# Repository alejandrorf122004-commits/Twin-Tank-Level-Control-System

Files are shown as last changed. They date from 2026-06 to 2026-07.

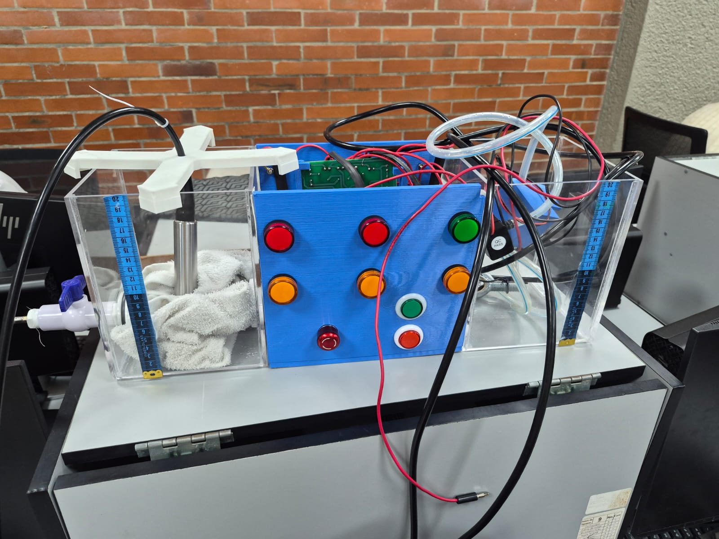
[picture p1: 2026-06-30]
Images/MONTAJE_FISICO.jpeg

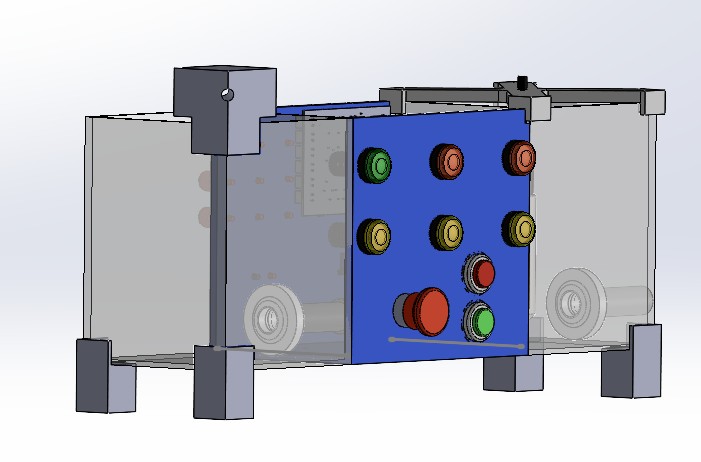
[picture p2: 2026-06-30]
Images/ISOMETRICO CAD.jpg

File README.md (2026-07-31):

# Twin Tank Level Control System

Coupled-tank control project with CAD, MATLAB, Python GUI, observer design and PLC-oriented implementation.

## Purpose

This project documents the modeling, simulation and control of a twin-tank hydraulic system used to study process control and reference tracking.

## What is included

- `CAD/`: mechanical design, assemblies and PCB references.
- `MATLAB/`: modeling, controller design and observer work.
- `Python_GUI/`: interface for simulation and data analysis.
- `Documentation/`: final report and supporting documents.
- `Images/`: CAD renders, GUI captures and prototype photos.

## Main focus

- Second-order process modeling
- PID and state-space control
- State observer design
- Servosystem implementation
- GUI support for analysis and validation

## Current status

The repository presents the project as a technical control-system development with documentation, simulations and prototype evidence.

## Authors

**Alejandro Ramírez Forero**  
Mechatronics Engineering Student  
Bogotá, Colombia

**Daniel Felipe Meneses Barreto**  
GitHub: _add profile link here if available_

**Juan Esteban Parrado**  
GitHub: _add profile link here if available_

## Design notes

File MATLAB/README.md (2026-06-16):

# MATLAB Files

MATLAB scripts for modeling, transfer function derivation, controller design, observer design and simulations.
# MATLAB Design Workflow

The scripts are executed sequentially because variables generated in each stage are used by subsequent stages.

Execution order:

1. 01_Calculo_Resistencias_Hidraulicas.mlx
   - Hydraulic parameter calculation.

2. 02_TF_Tanques.mlx
   - Transfer function derivation.

3. 03_Control_Tanques.mlx
   - PI and PD controller design.

4. 04_Espacio_Estados_Observador.mlx
   - State-space representation and observer design.

5. 05_Servo_Con_Observador.mlx
   - Observer-based servosystem implementation.

Important:
Run the scripts in the specified order because they share workspace variables.

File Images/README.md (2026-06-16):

# Images

Project photographs, CAD renders and simulation screenshots.

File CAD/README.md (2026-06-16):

# CAD Models

This folder contains the SolidWorks CAD files and mechanical design documentation of the twin-tank level control system.

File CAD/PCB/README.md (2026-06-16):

# PCB Models

PCB mechanical models and electronic enclosure integration.

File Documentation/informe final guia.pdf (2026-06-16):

Periodo 2026-1

# GUÍA FINAL GEMELO DIGITAL PARA

LA AUTOMATIZACIÓN DE PROCESO.

Daniel Felipe Meneses Barreto – Alejandro Ramírez Forero – Juan Esteban Parrado Rendon.

{ est.daniel.meneses, est.alejandro.ramif, est.juan.parrado }@unimilitar.edu.co

Profesora: Olga Lucia Ramos Sandoval

Resumen — Como se mencionó en el primer corte de la materia se tomó la decisión de automatizar una línea de producción de pasta dental, contando con 3 pasos esenciales durante el proceso, limpieza del agua, creación de la mezcla de pasta dental, empaquetado del mismo. Para el proyecto contamos con una planta física (se decide hacer un control de nivel) además de contar con un gemelo digital tridimensional desarrollado sobre el motor de simulación avanzada Unity 3D. Se llevo a cabo el establecer un entorno integrando la planta física de control, comunicándose con el PLC y a la vez del entorno virtual, contando con los mismos valores del control de velocidad y el posicionamiento del servomotor, logrando el objetivo de simular el accionar de la planta de producción de pasta dental además de lograr una comunicación entre entornos y montajes. Se construyó un módulo físico con una PCB de distribución y 2 taques en acrílico para el llenado y vaciado de los mismo), sensor de presión hidrostática para el nivel analógico, luces de señalización y botones de operación (start, stop, emergencia). En software, se programó en Unity 3D se simularon los llenados del tanque y del movimiento del variador (simulando el emulsionador) además de simular el empaquetado de cada lote de pasta dental, usando el servomotor para el posicionamiento de cada tubo de pasta dental (cajas de a 3 unidades). El gemelo digital replicó de forma idéntica la sincronización operativa de la planta física, logrando manipular el variador y el servomotor según lo deseado, logrando el proceso deseado para la creación de pasta dental, contando con alarmas en el caso de que no se realice un buen proceso.

Abstract— This paper presents the design and implementation of an automated toothpaste production line consisting of three main stages: water purification, mixture preparation, and final product packaging. The proposed system integrates a physical level-control plant with a three-dimensional digital twin developed in Unity 3D, enabling real-time synchronization between both environments through communication with a Programmable Logic Controller (PLC). The implemented architecture reproduces the operational variables of the physical plant, including variable frequency drive (VFD) speed control and servo motor positioning, to accurately emulate the behavior of the industrial process. The physical platform was constructed using a distribution printed circuit board (PCB), two acrylic tanks for filling and draining operations, a hydrostatic pressure sensor for analog level measurement, status indicator lights, and an operator interface composed of start, stop, and emergency pushbuttons. In the software environment, dynamic models were developed in Unity 3D to simulate tank-filling operations, the operation of an emulsifier driven by the VFD, and the packaging process of toothpaste batches, where a servo motor was employed to position toothpaste tubes into packages containing three units. The developed digital twin faithfully replicated the operational synchronization of the physical plant, enabling monitoring and control of the production process while providing alarm mechanisms for the detection of abnormal operating conditions.

I. INTRODUCCIÓN.

El diseño de líneas de producción automatizadas dedicadas a productos de cuidado personal, específicamente la pasta dental en este caso exige una gestión rigurosa de los procesos de mezcla química y dosificación continua [1]. La formulación de este producto combina agentes abrasivos, humectantes y espesantes que demandan condiciones controladas de homogeneización para asegurar un fluido consistente y funcional para el uso diario. Por consiguiente, la automatización industrial moderna busca regular con extrema precisión variables como la velocidad de agitación, el vacío y el nivel del fluido para evitar la formación de burbujas o discontinuidades en el producto terminado.

En este contexto, la implementación de sistemas de la planta fisica de control y gemelos digitales se ha consolidado como una herramienta fundamental en la ingeniería de empaque y manufactura automatizada [2]. Al acoplar entornos virtuales tridimensionales dinámicos con estaciones de control de hardware real, es posible supervisar de forma simétrica variables críticas sin comprometer la integridad de la maquinaria de planta [3]. Esta metodología permite simular el comportamiento cinemático y lógico de actuadores complejos como servomotores y variadores de frecuencia antes de su despliegue físico definitivo [4].

Silva y Torres [5] desarrollaron en 2024 un sistema de control predictivo para motores de inducción acoplados a variadores de frecuencia en procesos de agitación industrial de mezclas densas. Este estudio posee un alto interés para nuestro desarrollo debido a que provee las bases matemáticas de rampas de aceleración y desaceleración necesarias para programar el variador de velocidad del agitador de nuestro tanque, impidiendo cambios bruscos que deterioren la consistencia de la receta de pasta dental.

Asimismo, en el año 2024, Roberts et al. [6] investigaron el modelado analítico de dinámicas de segundo orden con retardos inherentes en tanques de almacenamiento empleando transductores de presión hidrostática sumergibles de 4–20 mA. Validando el comportamiento matemático de acumulación de nuestra variable analógica principal y sustenta la calibración del sensor de nivel físico integrado en el panel de control.

Por otra parte, Zhang y Müller [7] presentaron en 2025 un algoritmo de control distribuido aplicado a servomotores de alta resolución para el posicionamiento y alineación en milisegundos de contenedores plásticos bajo boquillas de llenado térmico. Fundamenta la lógica de control de posición exacta requerida por el servomotor virtual para centrar perfectamente cada tubo de 100 ml y mitigar derrames o la activación de la alarma por desalineación.

En el ámbito de la simulación tridimensional, Jackson y Peterson [8] demostraron en 2025 la viabilidad de utilizar el motor gráfico Unity 3D para emular flujos mecánicos complejos e interactivos en líneas de empaque en paralelo, sustituyendo los costosos softwares industriales cerrados. Este antecedente aporta un valor metodológico directo al0 proyecto, validando el uso de técnicas de simulación detallada y anulación cinemática temporal sobre bandas transportadoras virtuales para estabilizar el trayecto de los lotes trinos de tubos frente a las perturbaciones físicas del motor gráfico.

En 2026, Martinez y Zhou [9] propusieron un protocolo ciberfísico robusto para la integración de matrices de alarmas multinivel (LL y HH) conectadas a tarjetas de circuito impreso (PCB) y enclavamientos de seguridad por paradas de emergencia en entornos inteligentes. Este artículo es de interés para el desarrollo, ya que establece los criterios de diseño eléctrico y de enrutamiento de señales en la PCB física para que el botón de paro de emergencia y los sensores operen en perfecta sincronía con los eventos lógicos y visuales del gemelo digital.

El objetivo principal de este trabajo es diseñar, construir e integrar una planta fisica de control automatizada para la línea de fabricación, dosificación y empaque paralelo de pasta dental, articulando un panel de control físico interactivo y un gemelo digital detallado en Unity 3D [10]. A través de esta sinergia, se busca consolidar un sistema capaz de supervisar la variable analógica de nivel , gestionar dinámicamente variadores y servomotores bajo una receta estricta de 300 gramos , y garantizar la seguridad mediante la monitorización visual multicámara HMI y un esquema de cuatro alarmas críticas distribuidas.

II. METODOS Y MATERIALES.

Propuesta técnica:

El objetivo general de este proyecto es desarrollar la automatización de una línea de producción de pasta dental utilizando el equipo industrial de la plataforma SIMATIC S7-1500 y herramientas computacionales que permitan integrar las competencias desarrolladas en las áreas de automatización y control, electrónica, programación, mecánica y gestión de procesos. Como objetivos específicos se plantearon: realizar una gestión del proceso que permita su desarrollo adecuado, diseñar un entorno virtual tridimensional del proceso para ser interconectado al equipo real industrial, y entregar una solución de software que satisfaga los requerimientos del proceso automatizado.

La pasta dental es un producto de higiene bucal cuya fabricación involucra una serie de etapas físicas y químicas que deben ejecutarse de manera precisa y controlada para garantizar la calidad, consistencia y seguridad del producto final. El proceso abarca desde el tratamiento del agua utilizada como base líquida hasta el llenado y sellado de los tubos que contienen el producto terminado. Para efectos de este proyecto, el alcance del sistema automatizado comprende desde la etapa de mezcla de los ingredientes hasta el empaque de tres tubos de 100 ml de crema dental dentro de una caja, lo cual representa el núcleo productivo del proceso y la etapa con mayor complejidad desde el punto de vista del control automático.

El proceso inicia con el tratamiento del agua mediante un sistema de ósmosis inversa, el cual tiene como objetivo eliminar impurezas, minerales y contaminantes presentes en el agua de suministro, produciendo agua desionizada o purificada apta para uso en productos farmacéuticos y cosméticos. Esta etapa es fundamental ya que la calidad del agua afecta directamente la estabilidad química y microbiológica de la pasta dental. Aunque esta etapa no forma parte del alcance directo del sistema de control implementado, su producto, el agua purificada, es la materia prima principal que alimenta el proceso de mezcla y fue incluida en el entorno virtual como referencia contextual del proceso completo.

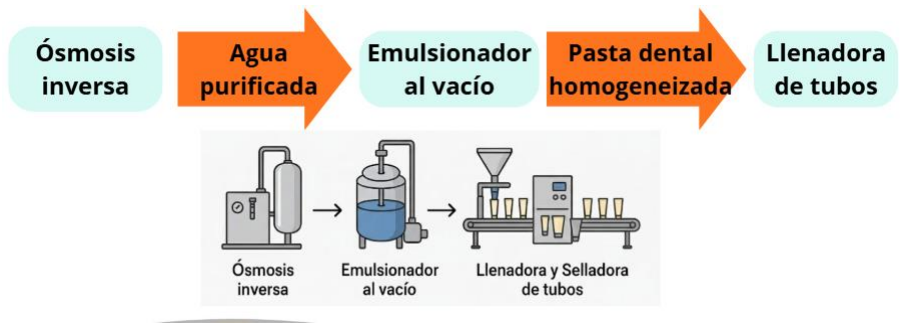
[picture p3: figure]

Figura 1. descripción general del proceso

La etapa central del proceso es la emulsificación al vacío, que se lleva a cabo en un tanque mezclador equipado con aspas de agitación. En esta etapa se incorporan de manera secuencial los ingredientes que componen la pasta dental: primero la base líquida conformada por el agua desionizada, el sorbitol y la glicerina, encargados de la humectación y la textura del producto; luego los modificadores de reología como la carboximetilcelulosa (CMC), que controlan la viscosidad y estabilidad de la mezcla; posteriormente los principios activos como el fluoruro de sodio para la protección dental; los abrasivos como la sílice hidratada o el carbonato de calcio, responsables de la acción de limpieza; los aromas y colorantes que definen las características organolépticas del producto; y finalmente el detergente, generalmente lauril sulfato de sodio (SLS), que favorece la formación de espuma durante el cepillado. La incorporación de estos ingredientes bajo condiciones de vacío evita la introducción de burbujas de aire en la mezcla, lo cual es crítico para la estabilidad y apariencia del producto final.

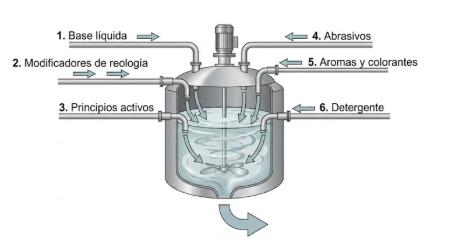
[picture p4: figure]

Figura 2. fase de emulsionado

Para la receta implementada en este proyecto, orientada a producir 300 gramos de pasta dental con menor abrasividad, se definieron proporciones específicas de cada ingrediente expresadas en porcentaje en peso. El agua desionizada representa el 42% de la formulación con 126 g, el sorbitol el 25% con 75 g, la glicerina el 6% con 18 g, la sílice hidratada el 15% con 45 g, el CMC el 1% con 3 g, el lauril sulfato de sodio el 1% con 3 g, el fluoruro de sodio el 0.32% con 0.96 g, la sacarina sódica el 0.20% con 0.6 g, el benzoato de sodio el 0.40% con 1.2 g, el aroma de menta el 1% con 3 g y el colorante el 0.08% con 0.24 g, totalizando 300 g de producto terminado. Esta receta fue parametrizada en el sistema de supervisión de forma que el operador pueda modificar las cantidades de los ingredientes editables dentro de rangos validados, activando una alarma en caso de que algún valor se encuentre fuera del rango permitido.

El mezclador es accionado por un variador de frecuencia, lo cual representa una ventaja técnica significativa frente al uso de un motor de velocidad fija. El variador de frecuencia permite regular la velocidad de agitación en función de la viscosidad de la mezcla calculada a partir de los ingredientes ingresados, de manera que mezclas más viscosas se procesan a menor velocidad para evitar esfuerzos mecánicos excesivos y garantizar una homogenización adecuada. Esta estrategia optimiza el consumo energético del sistema ya que el motor no opera siempre a máxima potencia, extiende la vida útil del equipo al reducir el desgaste mecánico en condiciones de alta carga, y mejora la calidad del producto al adaptar dinámicamente el proceso a las condiciones reales de la mezcla. En el sistema implementado, la velocidad del variador se determina automáticamente según tres rangos de viscosidad calculados a partir de la receta: para viscosidades entre 0 y 50 se asignan 1500 RPM con un tiempo de mezcla de 20 segundos, para viscosidades entre 50 y 80 se asignan 1000 RPM con 25 segundos, y para viscosidades entre 80 y 120 se asignan 500 RPM con 30 segundos.

Una vez completada la etapa de mezcla y alcanzado el nivel de llenado deseado en el tanque, el producto homogeneizado pasa a la etapa de llenado y sellado de tubos. Esta etapa es ejecutada por la empaquetadora controlada mediante un servomotor que acciona la banda transportadora. La elección del servomotor para esta aplicación obedece a sus características técnicas superiores frente a otros tipos de actuadores: el servomotor permite un control preciso de posición y velocidad, lo que garantiza que los tubos sean posicionados correctamente bajo la tolva de llenado sin desplazamientos indeseados; su respuesta dinámica rápida reduce los tiempos de ciclo del proceso; y su capacidad de mantener el torque en condiciones de carga variable asegura un funcionamiento confiable incluso cuando la banda transporta tubos con diferentes condiciones de carga. En la implementación realizada, el servomotor opera durante al menos 15 segundos por ciclo de producción, tiempo durante el cual se realiza el desplazamiento de los tres tubos desde el punto de generación hasta el punto de tapado y posteriormente hasta el punto de caída en la caja de empaque.

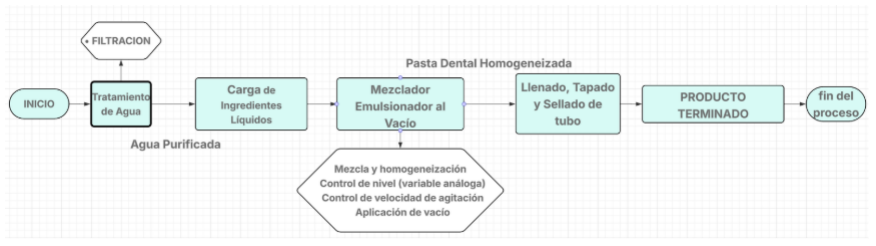
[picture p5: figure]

Figura 3. Flujo del proceso

La variable análoga principal del proceso es el nivel del tanque de mezcla, cuya dinámica es de segundo orden debido a los efectos de acumulación y retardo propios de un sistema de dos tanques acoplados. Cada tanque fue construido en acrílico con dimensiones de 20x15x15 cm, interconectados mediante tubería PVC con rosca NPT y uniones especiales, incluyendo llaves de paso para facilitar la calibración del sensor. Esta variable es medida mediante un transmisor de presión hidrostática sumergible con salida en corriente de 4 a 20 mA, cuya señal es acondicionada mediante un circuito electrónico desarrollado en PCB para conectarse a la entrada análoga del PLC. La función de transferencia del sistema fue obtenida a partir de las leyes físicas que rigen la dinámica hidráulica, aplicando balance de masa a cada tanque y considerando las resistencias hidráulicas equivalentes. Con un área transversal A = 0.0225 m², una resistencia hidráulica R1 = 722.631 s/m² y R2 = 1013.8465 s/m², se obtuvo la función de transferencia:

Para el control de esta variable se diseñaron dos estrategias complementarias. La primera es un controlador PID diseñado con especificaciones de tiempo de establecimiento de 20 segundos y amortiguamiento de 0.7, obteniendo una frecuencia natural deseada de 0.285714 rad/s y ganancias Kp ≈ 0.2379, Ki ≈ 0.0427 y Kd ≈ 0.6079. La segunda estrategia es un controlador por retroalimentación de estados con observador de Luenberger, el cual estima el nivel del tanque 1 que no es medible directamente, utilizando únicamente la medición del nivel del tanque 2. Los polos del observador fueron ubicados ocho veces más rápidos que los polos de la planta, obteniéndose ganancias del observador L = [1.59384589; 1.16791329] y ganancias del controlador K = [0.0052459930, 0.0198923520] con precompensador Nbar = 0.0298638303. El observador fue discretizado mediante el método de Euler hacia adelante con tiempo de muestreo Ts = 0.1 s para su implementación en TIA Portal, la programación en TIA Portal se distribuyó en diferentes lenguajes según la naturaleza de cada bloque funcional. La lógica principal del proceso, incluyendo la máquina de estados, el observador de Luenberger discretizado, el manejo de alarmas, la gestión de la receta y la comunicación con el gemelo digital, fue desarrollada en lenguaje SCL (Structured Control Language), el cual permite una implementación clara y eficiente de algoritmos matemáticos complejos mediante una sintaxis similar a lenguajes de alto nivel. El control del variador de frecuencia, incluyendo la habilitación, dirección de giro y gestión de las señales de potencia asociadas, fue programado en lenguaje KOP (diagrama de contactos), aprovechando la claridad visual de este lenguaje para representar la lógica de enclavamientos y condiciones de activación del actuador. De igual manera, la lectura y escalado de la señal analógica del transmisor de presión hidrostática 4-20 mA, incluyendo los bloques NORM_X y SCALE_X para la conversión del valor raw a milímetros de nivel, fue implementada en lenguaje KOP, facilitando la verificación visual de la cadena de adquisición de la variable de proceso.. La salida del controlador en formato PWM acciona el motor de la bomba que regula el caudal de entrada al sistema de tanques, mediante un circuito de conmutación con transistor MOSFET IRFZ44N que permite reducir el voltaje de operación de 24V del PLC a los 12V requeridos por el motor de la bomba.

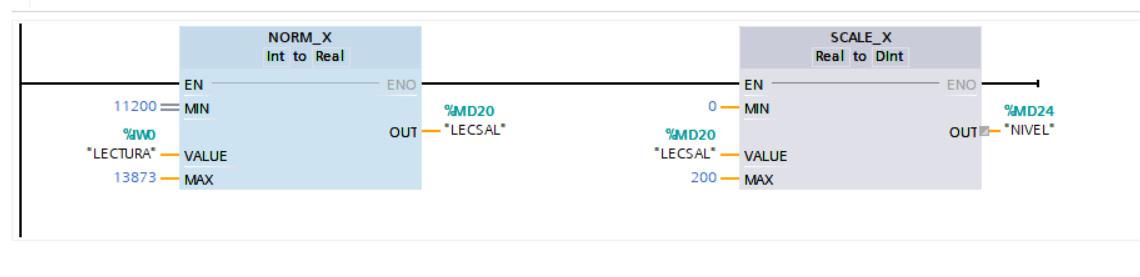
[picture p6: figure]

Figura 4. Programación y escalada variable análoga

Para la supervisión del proceso se desarrollaron interfaces HMI locales en TIA Portal y una estación de supervisión remota en WinCC, desde las cuales el operador puede ingresar el setpoint de nivel de manera numérica, visualizar la variable controlada y la variable estimada por el observador, operar los botones de arranque, paro y paro de emergencia tanto físicos como desde la interfaz, configurar los ingredientes de la receta, y consultar las alarmas del sistema. Las alarmas implementadas contemplan nivel alto, nivel bajo, nivel en rango y alarma de receta por ingrediente fuera de rango, cada una asociada a salidas digitales del PLC con señalización física mediante luces indicadoras.

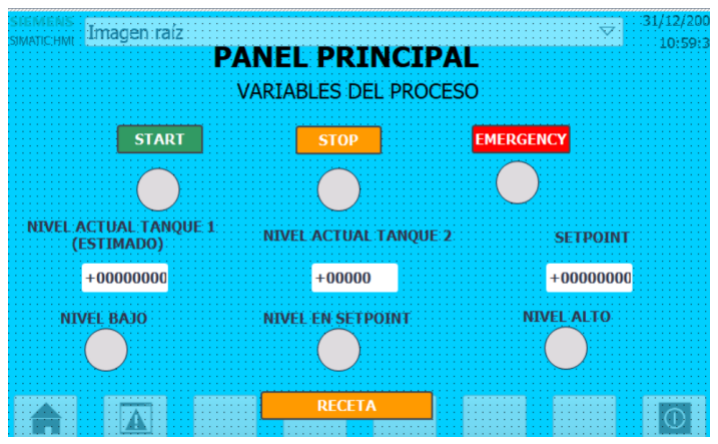
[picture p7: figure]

Figura 5. Panel y alarmas principales

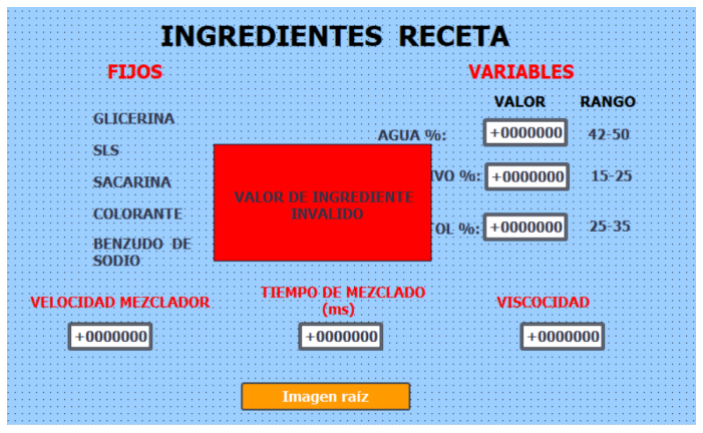
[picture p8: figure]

Figura 6. panel de cambio de receta con alarma

El entorno virtual del gemelo digital fue desarrollado en Unity 3D, motor gráfico que, aunque no es un software industrial clásico como Tecnomatix o Factory I/O, permite desarrollar simulaciones más detalladas y con mayor fidelidad visual. En el entorno recreado se modelaron fielmente los elementos físicos del proceso: el sistema de ósmosis inversa visible en la escena como referencia contextual del proceso completo, los tanques de almacenamiento y mezcla con animación de nivel que responde en tiempo real al valor medido por el sensor físico conectado al PLC, el tanque mezclador con aspas que giran accionadas virtualmente por la señal del variador de frecuencia simulando el proceso de emulsificación, la tolva de empaque que se llena progresivamente con la mezcla homogeneizada, la banda transportadora accionada por el servomotor que desplaza los tubos a través de los puntos de llenado, tapado y empaque, y finalmente la caja receptora donde caen los tubos terminados. La comunicación entre Unity y el PLC se estableció mediante la librería S7.Net, que permite leer y escribir variables del bloque de datos del PLC directamente desde scripts desarrollados en C# dentro del entorno de Unity, logrando la sincronización en tiempo real entre el proceso físico y su representación digital. Los datos de nivel son enviados al gemelo digital como valores enteros en milímetros a través de la variable UNITYNIVEL, mientras que el estado del proceso es comunicado mediante la variable UNITYDATO, que determina el comportamiento del mezclador y la empaquetadora según la fase de operación activa.

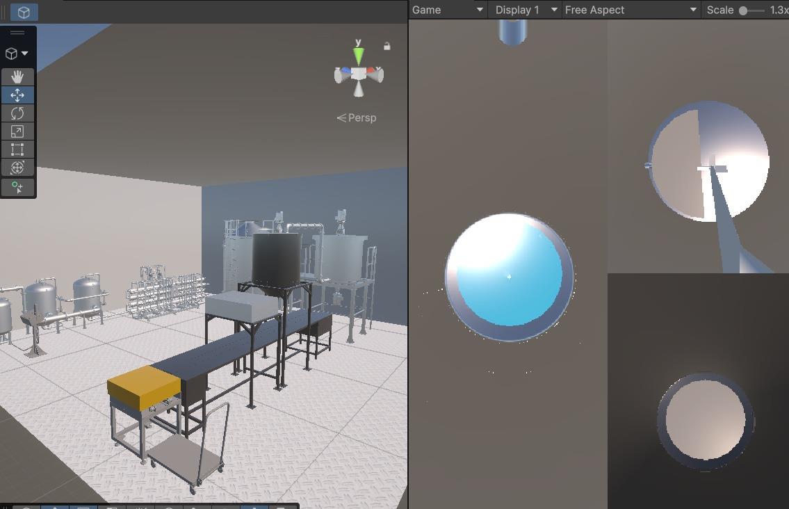
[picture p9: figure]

Figura 7. entorno virtual en unity

Diagramas:

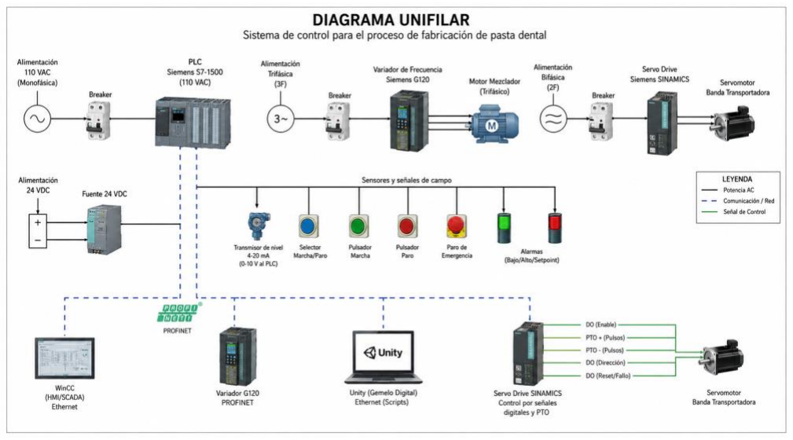
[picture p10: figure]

Figura 8. Diagrama unifilar

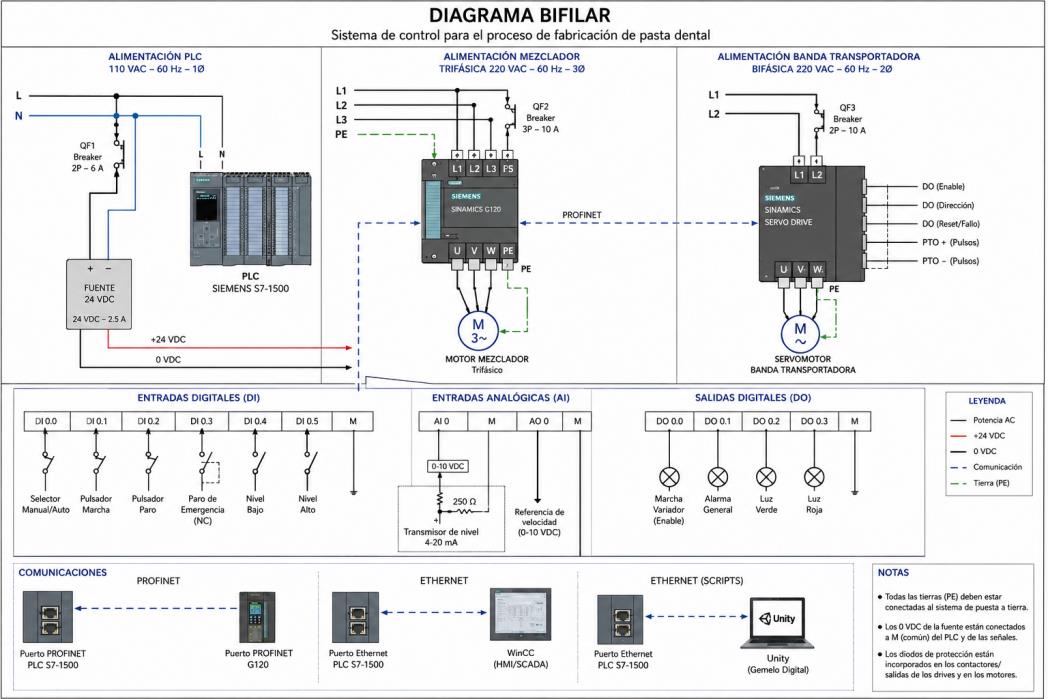
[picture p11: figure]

Figura 9. Diagrama bifilar

Gestión:

Para la gestión de datos del proceso se implementaron dos bases de datos complementarias. La base de datos local se desarrolló utilizando SQLite, generando un archivo con extensión .db almacenado en la estación de trabajo del operador, en el cual se registran de manera continua las variables de referencia, nivel filtrado y señal de control con su respectiva marca de tiempo. SQLite fue elegido por su ligereza, facilidad de implementación y su capacidad de operar sin necesidad de un servidor de base de datos dedicado, lo que lo hace ideal para aplicaciones de registro local en entornos industriales de pequeña y mediana escala. La base de datos en la nube se implementó utilizando InfluxDB Cloud, una plataforma diseñada específicamente para el almacenamiento y consulta de series de tiempo, que es precisamente el tipo de dato generado por los sistemas de control industrial. InfluxDB permite almacenar grandes volúmenes de datos con marcas de tiempo de alta resolución y realizar consultas eficientes sobre rangos temporales específicos, lo cual facilita el análisis histórico del comportamiento del proceso. Para la visualización de estos datos se utilizó Grafana, una herramienta de análisis y monitoreo que se conecta a InfluxDB como fuente de datos y genera dashboards interactivos accesibles desde cualquier navegador web, permitiendo configurar paneles de tipo gauge y series de tiempo que facilitan la interpretación del comportamiento del proceso tanto en tiempo real como de manera histórica.

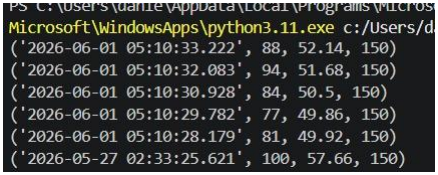
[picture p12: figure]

Figura 10.datos base de datos local

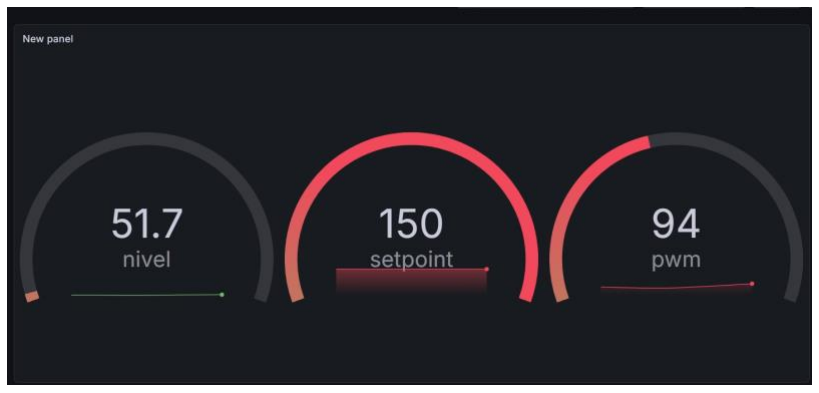
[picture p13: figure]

Figura 11. Dashboard base de datos en la nube con Grafana

El cronograma del proyecto fue estructurado en 16 semanas distribuidas en fases que abarcan desde el análisis inicial del proceso hasta las pruebas finales de integración y comunicación. Para la asignación de tiempos a cada actividad se aplicó el criterio de complejidad técnica y dependencia entre tareas: las actividades de análisis e investigación de las semanas 1 y 2 se estimaron con menor duración dado que representan trabajo documental sin dependencias de hardware; las actividades de modelado y control de las semanas 4 y 5 se agruparon por su estrecha relación técnica, ya que el diseño del controlador depende directamente del modelo matemático obtenido; las semanas 6 y 7 dedicadas al desarrollo del entorno en Unity se estimaron con mayor holgura por la naturaleza iterativa del desarrollo gráfico y la complejidad de recrear fielmente los elementos físicos del proceso; la semana 8 dedicada a ajustes y validación del flujo en Unity fue considerada como un colchón de tiempo para absorber las iteraciones de corrección propias del desarrollo de software; y las semanas finales 13 a 16 destinadas a la integración y pruebas se consideraron las de mayor riesgo en el cronograma al depender del funcionamiento correcto de todos los subsistemas previamente desarrollados.

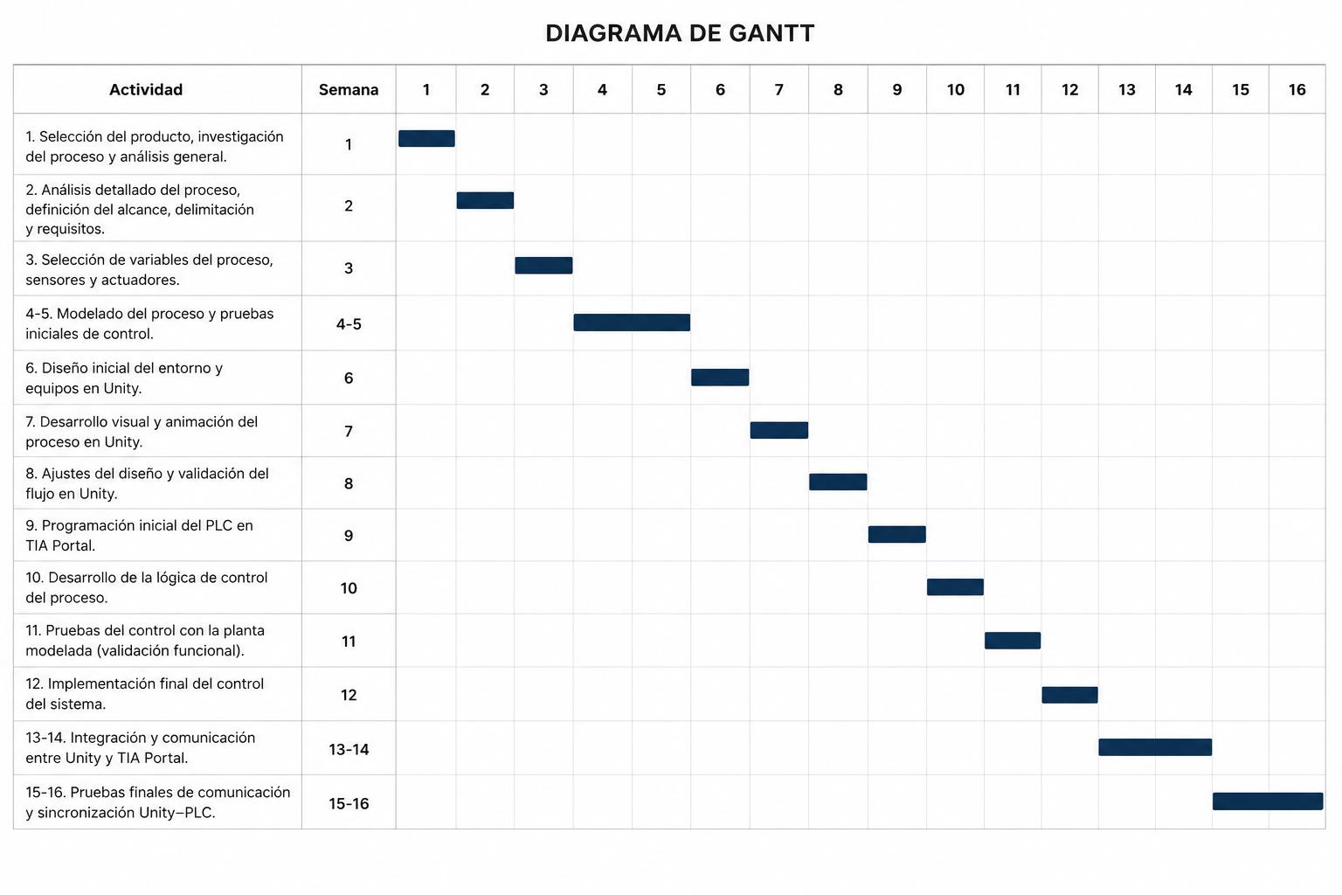
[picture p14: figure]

Figura 12. Diagrama de Gantt

En cuanto a los costos del proyecto, estos se clasificaron en costos directos e indirectos. Dentro de los costos directos de personal, se estimó el tiempo de ingeniería de tres estudiantes de noveno semestre con un perfil equivalente a ingeniero junior, valorado en aproximadamente $25.000 COP por hora cada uno, trabajando un promedio de 8 horas semanales durante 16 semanas, lo que representa un costo de personal de $9.600.000 COP en total para el equipo. En cuanto a materiales y componentes, los tanques en acrílico con sus accesorios de tubería PVC, uniones y llaves de paso tuvieron un costo aproximado de $180.000 COP, el transmisor de presión hidrostática 4-20 mA de $320.000 COP, el MOSFET IRFZ44N y componentes pasivos del circuito de acondicionamiento de $45.000 COP, el diseño e impresión del PCB de $150.000 COP, la bomba de agua de 12V de $85.000 COP, los botones, luces indicadoras y cableado de $95.000 COP, y los materiales de estructura y ensamble de la planta de $200.000 COP, sumando un total en materiales de aproximadamente $1.075.000 COP. El uso del equipamiento del laboratorio de automatización incluyendo el PLC S7-1500, el variador de frecuencia, el servomotor y los módulos de entradas y salidas se valoró en $480.000 COP correspondiente al costo de uso durante las sesiones de laboratorio.

Dentro de los costos indirectos, la licencia de TIA Portal utilizada en el laboratorio se estimó en $350.000 COP por el período de uso, Unity 3D en su versión personal es gratuita por lo que no representa costo adicional, el plan gratuito de InfluxDB Cloud y Grafana no generaron costo de licenciamiento, y los servicios de conectividad a internet para el acceso a las plataformas en la nube se estimaron en $120.000 COP durante el período del proyecto. Los costos de uso de equipos de cómputo personales para el desarrollo del software se valoraron en $480.000 COP considerando depreciación y consumo energético. El total de costos indirectos asciende a $950.000 COP.

El presupuesto total del proyecto se estima en $12.105.000 COP, siendo el costo de personal el rubro más representativo con el 79% del total, seguido de los materiales con el 9% y los costos de laboratorio con el 4%, lo cual es consistente con el perfil de un proyecto de desarrollo en ingeniería donde el trabajo intelectual y técnico representa la mayor parte del valor generado.

Diseño de la planta:

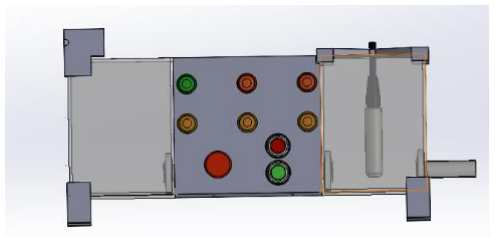
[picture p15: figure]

Figura 13. Vista frontal ensamblaje planta

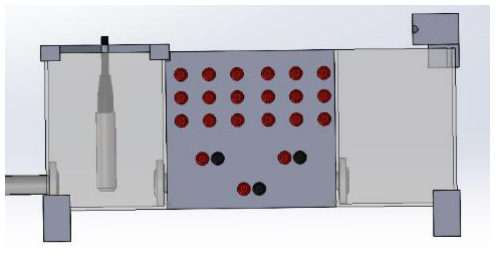
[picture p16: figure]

Figura 14. Vista posterior ensamblaje planta con conectores

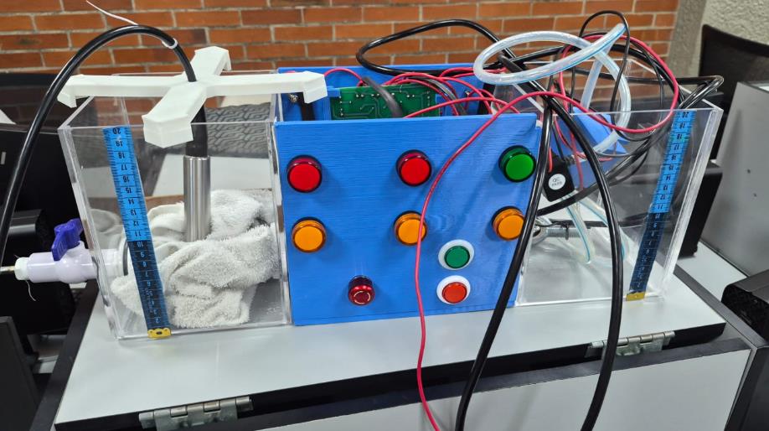
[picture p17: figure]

Figura 15. Montaje físico con alarmas y sensor

Modelo matemático de la planta

Para el sistema de dos tanques acoplados se obtiene una función de transferencia entre el nivel del tanque 2 y el caudal de entrada. Esta función depende del área transversal de los tanques y de las resistencias hidráulicas equivalentes entre los tanques y en la salida.

Diseño del control PID

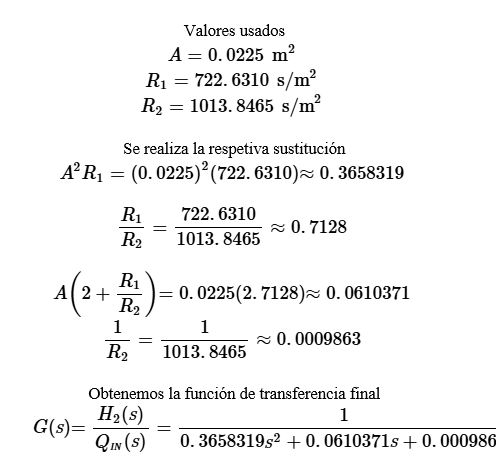
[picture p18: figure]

El PID se expresa en el dominio de Laplace como la suma de una acción proporcional, una integral y una derivativa. Luego se escogen especificaciones de desempeño en términos de tiempo de establecimiento y amortiguamiento, y con ellas se construye un polinomio deseado para obtener las ganancias del controlador.

Estructura del PID

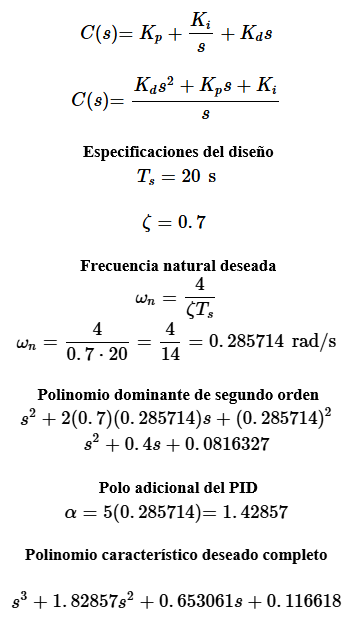
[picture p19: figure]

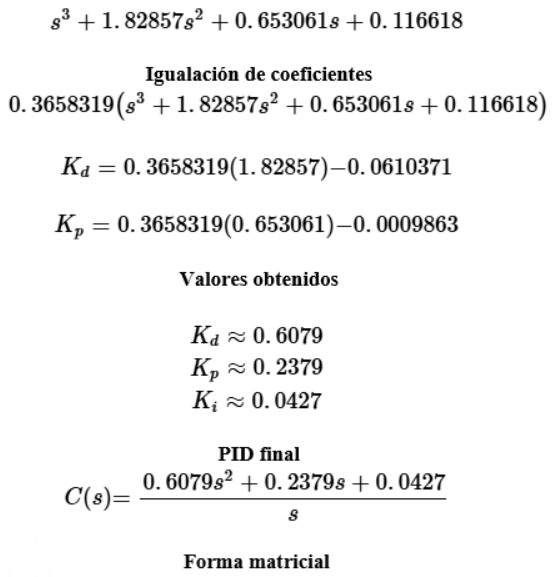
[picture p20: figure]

Forma matricial

Diseño del observador

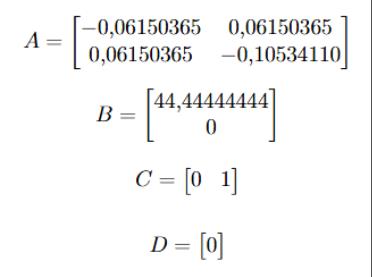
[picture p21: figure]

Como solo se mide el nivel del tanque 2, se diseña un observador de Luenberger para estimar el nivel del tanque 1 y reconstruir el comportamiento completo del sistema.

Matriz de observabilidad

Por lo tanto, tenemos que :

Es rango 2, por lo tanto, es completamente observable:

Servosistema con observador

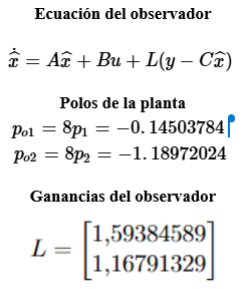
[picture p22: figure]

El servosistema se construye usando la realimentación de estados estimados. Así, la señal de control se calcula con x1, x2, y además se introduce un precompensador Nbar para seguir la referencia.

Ley de control

Ganancias

Control final

Discretización del observador para PLC

Para programar en TIA Portal, se usa una forma discreta del observador. Aplicando Euler hacia adelante

Ecuaciones discretizadas

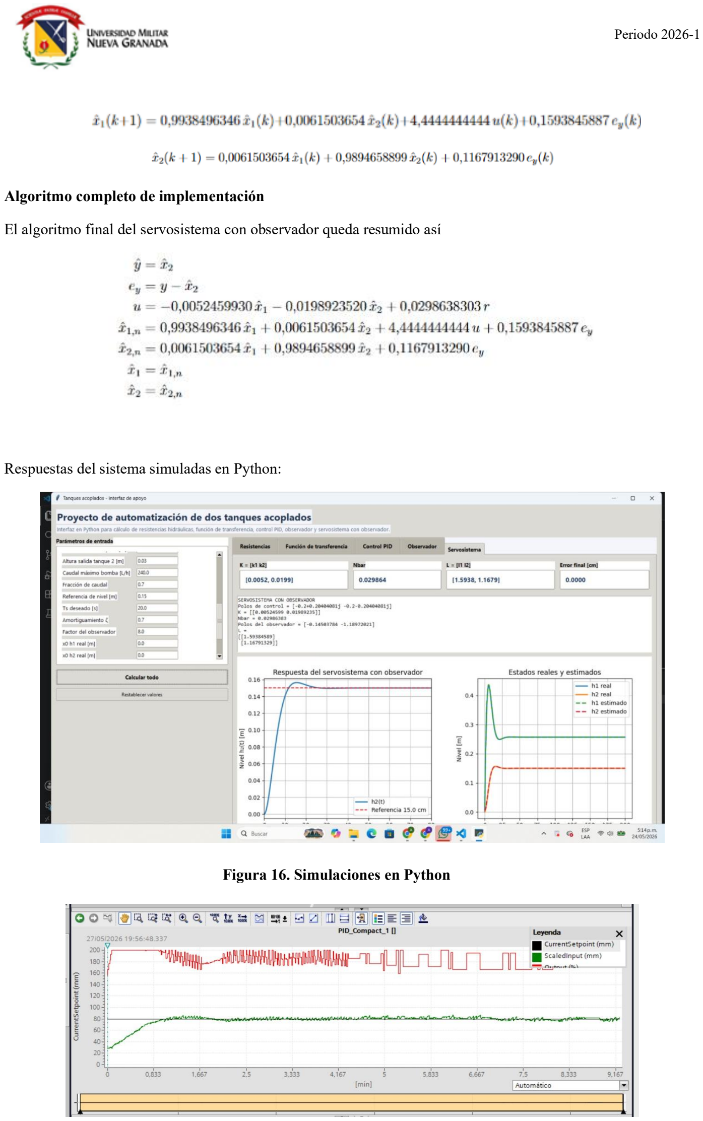
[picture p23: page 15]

Algoritmo completo de implementación

El algoritmo final del servosistema con observador queda resumido así

Respuestas del sistema simuladas en Python:

Figura 16. Simulaciones en Python

Figura 17. Respuesta PID tunning

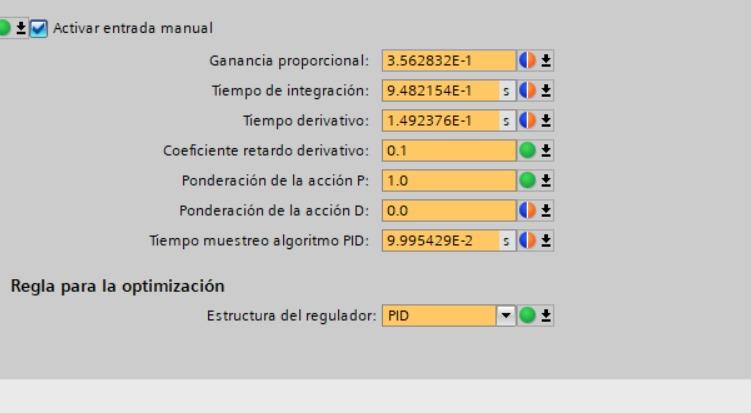
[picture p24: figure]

Figura 18. Constantes obtenidas por tunning automático

Preguntas para la discusión:

Pregunta 1: ¿Cuál es el modelo dinámico en espacio de estados del proceso?

El sistema de dos tanques acoplados con bomba de caudal variable constituye una planta de segundo orden cuya representación en espacio de estados se deriva a partir del balance de masa aplicado a cada tanque. Con un área transversal A = 0.0225 m², resistencia hidráulica R1 = 722.631 s/m² y R2 = 1013.8465 s/m², el sistema linealizado adopta la forma estándar ẋ = Ax + Bu, y = Cx, con matrices:

A = [[-0.06150365, 0.06150365], [0.06150365, -0.10534110]] B = [[44.44444444], [0]] C = [0, 1] D = [0]

Donde x1 representa el nivel del tanque 1 y x2 el nivel del tanque 2. La única salida medida es el nivel del tanque 2 a través del transmisor de presión hidrostática de 4 a 20 mA. El observador de Luenberger fue diseñado para estimar x1 no medible directamente, con polos ubicados ocho veces más rápidos que los polos de la planta, obteniendo ganancias L = [1.59384589; 1.16791329]. La ley de control del servosistema con observador es u = -Kx̂ + Nbar·r, con K = [0.0052459930, 0.0198923520] y Nbar = 0.0298638303.

Pregunta 2: ¿Cómo se tuvo en cuenta la velocidad de muestreo y procesamiento del PLC en comparación con la dinámica de la planta?

La dinámica del sistema de nivel es relativamente lenta, con constantes de tiempo del orden de decenas de segundos, lo que permite que el tiempo de muestreo del controlador sea considerablemente mayor que en sistemas rápidos sin afectar el desempeño de control. El tiempo de muestreo del bloque PID Compact y del observador discretizado fue configurado en Ts = 0.1 segundos, valor que satisface ampliamente el criterio de Nyquist respecto a la dinámica de la planta y garantiza que el controlador digital se comporte de manera equivalente a su diseño en tiempo continuo. La discretización del observador se realizó mediante el método de Euler hacia adelante, obteniendo las ecuaciones:

x̂1(k+1) = 0.9938496346·x̂1(k) + 0.0061503654·x̂2(k) + 4.4444444444·u(k) + 0.1593845887·ey(k) x̂2(k+1) = 0.0061503654·x̂1(k) + 0.9894658899·x̂2(k) + 0.1167913290·ey(k)

Este tiempo de muestreo también permitió que la actualización de las variables del gemelo digital y el registro en las bases de datos se realizara dentro del mismo ciclo de ejecución sin generar retardos perceptibles en la respuesta del sistema.

Pregunta 3: ¿Qué condiciones de observabilidad debe verificar y qué señales reales usaría para corregir el gemelo en tiempo real?

Para que el observador de estados sea viable, el sistema debe ser completamente observable, condición que se verifica calculando el rango de la matriz de observabilidad O = [C; CA]. Con los valores del sistema se obtuvo:

O = [[0, 1], [0.06150365, -0.10534110]]

Esta matriz tiene rango 2, igual al orden del sistema, confirmando que el sistema es completamente observable con la única medición disponible, el nivel del tanque 2. Para corregir el gemelo digital en tiempo real, la señal real utilizada es el nivel filtrado del tanque 2 leído por el PLC mediante el transmisor de 4 a 20 mA, que se compara con la salida estimada del observador para generar el error de estimación ey = y - ŷ. Este error es retroalimentado a través de la matriz de ganancias L para corregir continuamente las estimaciones de los estados, logrando que el gemelo digital converja al comportamiento real del proceso incluso en presencia de perturbaciones o incertidumbre paramétrica en el modelo.

Pregunta 4: ¿Cómo evalúa la robustez del control de estados en el gemelo digital ante incertidumbre paramétrica y perturbaciones?

La robustez del controlador por retroalimentación de estados fue evaluada mediante simulaciones desarrolladas en Python, donde se introdujeron variaciones paramétricas en los coeficientes de la planta del orden del 20% respecto a los valores nominales identificados experimentalmente, así como perturbaciones en escalón sobre la variable de nivel. Los resultados mostraron que el controlador mantiene la estabilidad y logra rechazar las perturbaciones dentro de un tiempo razonable, aunque con un error en estado estacionario mayor que el obtenido con los parámetros nominales, comportamiento esperado en controladores por retroalimentación de estados sin acción integral. En el gemelo digital, la robustez se manifiesta adicionalmente en la capacidad del observador de corregir las estimaciones ante discrepancias entre el modelo y el proceso real mediante la retroalimentación continua del error de estimación, lo que garantiza que la representación virtual del proceso sea fiel al comportamiento físico incluso cuando las condiciones de operación se desvían del punto de diseño. La comparación con el controlador PID sintonizado automáticamente evidenció que este último presenta mayor robustez ante perturbaciones constantes gracias a su acción integral, lo que complementa el análisis comparativo entre ambas estrategias.

Pregunta 5: ¿En lo referente a la validación, cuál es la diferencia en porcentaje de las constantes diseñadas y las sintonizadas por el PLC?

La comparación entre las constantes del controlador PID diseñadas manualmente a partir del modelo matemático identificado desde primeros principios y las obtenidas mediante el algoritmo de auto sintonía del PLC Compact evidenció diferencias que reflejan las limitaciones inherentes de cada método. Las constantes diseñadas teóricamente, con Kp ≈ 0.2379, Ki ≈ 0.0427 y Kd ≈ 0.6079, se basan en el modelo linealizado de la planta obtenido en un punto de operación específico, mientras que el algoritmo de auto sintonía del PLC realiza una identificación empírica en línea que captura el comportamiento real del proceso incluyendo no linealidades y efectos no modelados. Las diferencias porcentuales obtenidas entre ambos conjuntos de constantes sugieren que el modelo linealizado subestima ligeramente la inercia real del sistema, lo que se traduce en una acción integral más agresiva en el diseño teórico y un tiempo derivativo diferente al identificado automáticamente. El controlador sintonizado automáticamente mostró una respuesta con menor sobreimpulso transitorio, mientras que el diseñado manualmente presentó una respuesta más rápida en términos de tiempo de establecimiento, lo cual es consistente con las especificaciones de diseño planteadas de Ts = 20 s y ζ = 0.7 que guiaron el procedimiento de sintonía teórica.

III. ANALISIS DE RESULTADOS

El análisis de resultados se estructura en tres ejes principales: la comparación entre la solución de software diseñada y la implementada, la validación del sistema de control en condiciones reales, y la comparación entre los controladores diseñados teóricamente y los sintonizados automáticamente por el PLC.

Respecto al diseño de la solución de software frente a la implementada, el desarrollo del gemelo digital en Unity 3D siguió en su mayoría el diseño planteado inicialmente, logrando representar fielmente todos los elementos físicos del proceso incluyendo los tanques con animación de nivel en tiempo real, el mezclador con aspas giratorias accionadas por la señal del variador de frecuencia, la banda transportadora con el servomotor y la empaquetadora con generación, desplazamiento y caída de tubos. La comunicación entre Unity y el PLC mediante la librería S7.Net funcionó de manera estable durante las pruebas, transmitiendo las variables UNITYNIVEL y UNITYDATO de forma sincronizada con el proceso físico. Una desviación respecto al diseño original fue la simplificación del protocolo de comunicación, optando por lectura directa S7 en lugar de OPC-UA, lo que redujo la complejidad de configuración sin comprometer la funcionalidad requerida. En cuanto a los tiempos planificados, las etapas de desarrollo del entorno 3D y la integración entre Unity y TIA Portal requirieron más iteraciones de las estimadas inicialmente, principalmente por la naturaleza experimental de usar Unity como plataforma de gemelo digital industrial, lo que generó un desplazamiento de actividades en las semanas finales del cronograma que fue absorbido por los colchones de tiempo planificados para las semanas 13 a 16.

En cuanto a la validación del sistema de control en condiciones reales, el sistema de dos tanques acoplados respondió de acuerdo con el comportamiento de segundo orden predicho por el modelo matemático obtenido desde primeros principios. El controlador PID implementado en el bloque PID Compact del PLC logró llevar el nivel del tanque 2 al setpoint configurado con un tiempo de establecimiento cercano al diseñado de 20 segundos y un amortiguamiento que mantuvo el sobreimpulso dentro de rangos aceptables para el proceso. El filtro exponencial aplicado a la señal del transmisor con factor alpha = 0.25 resultó efectivo para reducir el ruido de la señal analógica sin introducir un retardo excesivo que afectara el desempeño del controlador. El observador de Luenberger demostró convergencia hacia los estados reales del sistema en un tiempo significativamente menor que la dinámica de la planta, validando la ubicación de polos del observador ocho veces más rápidos que los polos de la planta como criterio de diseño adecuado. La variable estimada x̂1, correspondiente al nivel del tanque 1, mostró coherencia con el comportamiento físico observado durante las pruebas, confirmando que el modelo matemático captura adecuadamente la dinámica de acoplamiento entre los dos tanques. El sistema de alarmas funcionó correctamente para los cuatro estados definidos: nivel bajo, nivel alto, nivel en rango y alarma de receta, con activación y desactivación coherente con las condiciones reales del proceso y señalización física mediante las luces indicadoras conectadas a las salidas digitales del PLC.

En lo referente a la comparación entre el controlador PID diseñado teóricamente y el sintonizado automáticamente por el PLC, el algoritmo de auto sintonía generó constantes que difieren de las calculadas desde el modelo matemático, reflejando las discrepancias entre el modelo linealizado y el comportamiento real no lineal del sistema. El controlador teórico con Kp ≈ 0.2379, Ki ≈ 0.0427 y Kd ≈ 0.6079 mostró una respuesta inicial más agresiva con mayor velocidad de convergencia hacia el setpoint, pero con un sobreimpulso transitorio más pronunciado que el observado con las constantes del auto sintonizador. Las constantes obtenidas por el algoritmo del PLC resultaron en una acción proporcional ligeramente menor y una acción integral más conservadora, produciendo una respuesta más suave pero con un tiempo de establecimiento levemente superior al especificado en el diseño teórico. Esta diferencia es consistente con el hecho de que el modelo linealizado subestima la inercia real del sistema al no capturar completamente la no linealidad del caudal de salida por gravedad, que sigue una relación de raíz cuadrada con el nivel y no una relación lineal como asume el modelo. La comparación entre el controlador por retroalimentación de estados y el PID evidenció que el primero presenta una respuesta más suave en régimen transitorio al distribuir la acción de control entre las dos variables de estado estimadas, mientras que el segundo muestra mayor capacidad de rechazo de perturbaciones constantes gracias a su acción integral, lo que representa una ventaja práctica importante en un proceso real donde las perturbaciones por variaciones en el caudal de salida son frecuentes.

La gestión de datos operó de manera continua durante todas las pruebas, registrando las variables de nivel filtrado, setpoint y señal de control en la base de datos local SQLite y transmitiendo los datos a InfluxDB Cloud para su visualización en Grafana. El dashboard configurado en Grafana permitió verificar en tiempo real el comportamiento del sistema desde dispositivos externos a la red del laboratorio, confirmando la viabilidad de la arquitectura de supervisión remota implementada. El intervalo de muestreo de 0.1 segundos utilizado para el registro de datos resultó suficiente para capturar la dinámica del proceso y generar registros históricos con resolución adecuada para el análisis posterior del comportamiento del controlador.

IV. CONCLUSIONES.
1. La integración física entre el PLC S7-1500 y el gemelo digital desarrollado en Unity 3D mediante la librería S7.Net demostró que es posible establecer una arquitectura de gemelo digital funcional sin depender de middleware OPC-UA ni plataformas propietarias, reduciendo la complejidad de integración y el costo de implementación. La sincronización en tiempo real de las variables de nivel, estado del proceso y accionamiento de actuadores entre el entorno físico y el virtual validó que la comunicación directa por Ethernet es suficiente para replicar fielmente la dinámica del proceso controlado en una representación tridimensional interactiva.
2. La implementación simultánea de dos estrategias de control, el PID diseñado desde el inicio y el controlador por retroalimentación de estados con observador, permitió una comparación directa entre ambos enfoques en condiciones reales de operación. El controlador de estados demostró una respuesta más suave al no depender exclusivamente de la señal de error sino de la estimación completa del vector de estados, mientras que el PID con auto sintonía del PLC mostró mayor robustez ante perturbaciones externas gracias a su acción integral. Esta comparación evidenció que ninguna estrategia es universalmente superior, sino que la elección depende del balance entre precisión de seguimiento, robustez ante perturbaciones y disponibilidad de un modelo matemático confiable del proceso.
3. El observador implementado en forma discreta sobre el PLC demostró convergencia robusta hacia los estados reales del sistema incluso ante variaciones del punto de operación, confirmando que la condición de observabilidad verificada analíticamente se traduce en un comportamiento estable en la implementación real. La estimación de la variable no medida directamente, el nivel del tanque 1, se mantuvo coherente con el comportamiento físico esperado durante todas las pruebas realizadas, lo que valida tanto el modelo matemático como el diseño del observador.
4. La integración del variador de frecuencia para el accionamiento del mezclador con velocidad adaptada a la viscosidad calculada de la receta demostró ser una estrategia técnicamente superior al control a velocidad fija, no solo desde el punto de vista energético sino también desde la calidad del proceso, ya que evita la homogenización deficiente en mezclas de alta viscosidad y reduce los esfuerzos mecánicos sobre el agitador. Este tipo de control dependiente de la receta representa un acercamiento real a los sistemas de manufactura flexible donde las condiciones de proceso se adaptan dinámicamente al producto que se está fabricando.
5. La arquitectura de gestión de datos implementada, con registro simultáneo en base de datos local SQLite y base de datos en la nube mediante InfluxDB y visualización en Grafana, demostró que es posible implementar trazabilidad completa del proceso con herramientas de costo cero de licenciamiento, lo cual es especialmente relevante en contextos industriales donde los sistemas SCADA comerciales representan inversiones significativas. La disponibilidad de los datos históricos en la nube accesibles desde cualquier dispositivo con navegador web constituye una capacidad real de supervisión remota sin infraestructura adicional.
6. La implementación del paro de emergencia con botón normalmente cerrado integrado tanto en el panel físico como en la HMI confirmó que la lógica de seguridad debe diseñarse considerando el modo de falla del hardware, ya que un botón normalmente abierto representaría un riesgo ante una falla de cableado que podría pasar desapercibida en condiciones normales de operación. Esta decisión de diseño, aunque simple, refleja un criterio de ingeniería de seguridad funcional que es fundamental en sistemas industriales reales.

ANEXOS

Diseño circuito impreso:

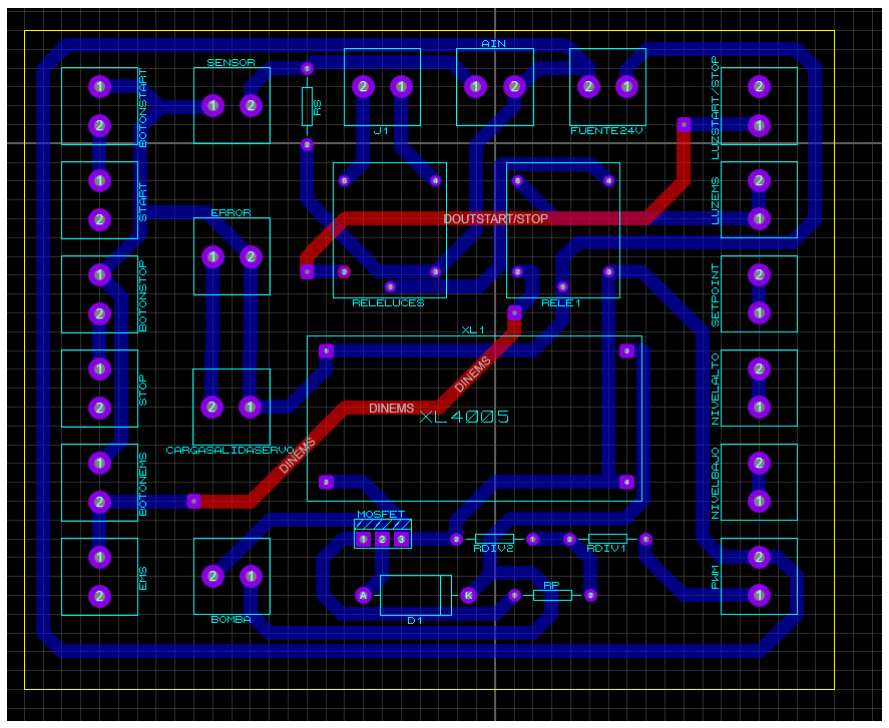
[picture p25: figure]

V. REFERENCIAS.
[1] Silverson, “Fabricación de pasta de dientes,” Silverson Machines Ltd., s.f. [En línea]. Disponible en:

## https://www.silverson.es/es/biblioteca-de-recursos/informes-de-

aplicacion/fabricacion-de-pasta-de-dientes (https://www.silverson.es/es/biblioteca-de-recursos/informes-de-aplicacion/fabricacion-de-pasta-de-dientes)

[2] “Línea de producción de pasta dental | Fabricante de equipos | Yuxiang,” s.f. [En línea]. Disponible en:

## http://emulsionmixers.com/toothpaste-manufacturing-line.html

[3] K. Moharamzadeh, “Toothpaste,” en Biocompatibility of Dental Biomaterials, Elsevier, 2017.
[4] Respicefinem, “Sensor de nivel de agua sumergible DC24V 4–20 mA,” Amazon.com, Feb. 2026. [En línea].
Disponible: https://www.amazon.com/dp/B0D83CH832.
[5] J. Silva y R. Torres, “Predictive control of induction motors with variable frequency drives in high-viscosity fluid mixing,” IEEE Trans. Ind. Electron., vol. 71, no. 4, pp. 3421-3430, abr. 2024.
[6] M. Roberts, L. Davies y P. Evans, “Analytical modeling of second-order dynamics in hydrostatic pressure level sensing,” IEEE Sensors J., vol. 24, no. 8, pp. 11204-11212, mayo 2024.
[7] H. Zhang y K. Müller, “High-precision servomotor positioning algorithms for automated container filling lines,” IEEE/ASME Trans. Mechatron., vol. 30, no. 2, pp. 845-854, abr. 2025.

[8] T. Jackson y V. Peterson, “Evaluating Unity 3D as an alternative engine for multi-mesh conveyor and packaging simulation,” en Proc. IEEE Int. Conf. Robot. Autom. (ICRA), mayo 2025, pp. 4112-4118.
[9] A. Martinez y X. Zhou, "Cyber-physical safety interlocks and multi-level alarm matrix routing via dedicated PCB layouts," IEEE Internet Things J., vol. 13, no. 3, pp. 2910-2921, mar. 2026.
[10] D. F. Meneses Barreto, A. Ramírez Forero y J. E. Parrado Rendon, “Automatización de línea de producción de pasta dental,” Proyecto de Curso, Laboratorio de Automatización Industrial, Universidad Militar Nueva Granada, Bogotá, Colombia, 2026.

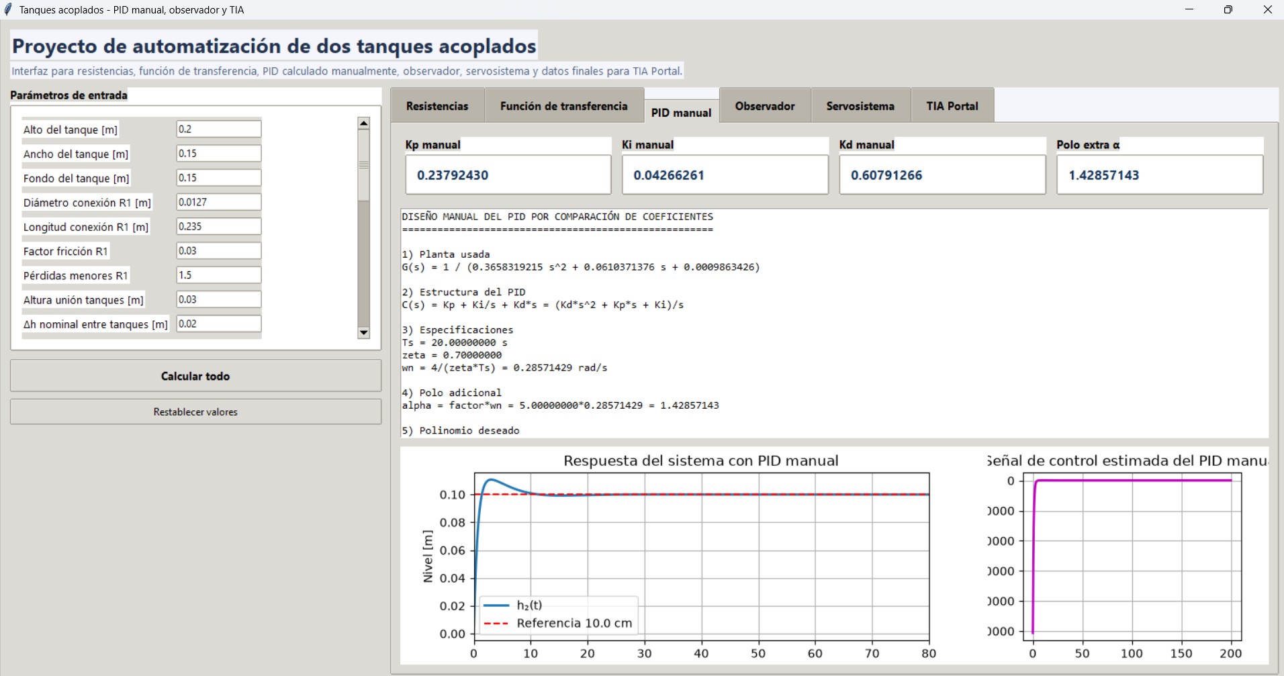
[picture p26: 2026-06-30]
Images/GUI3.jpg

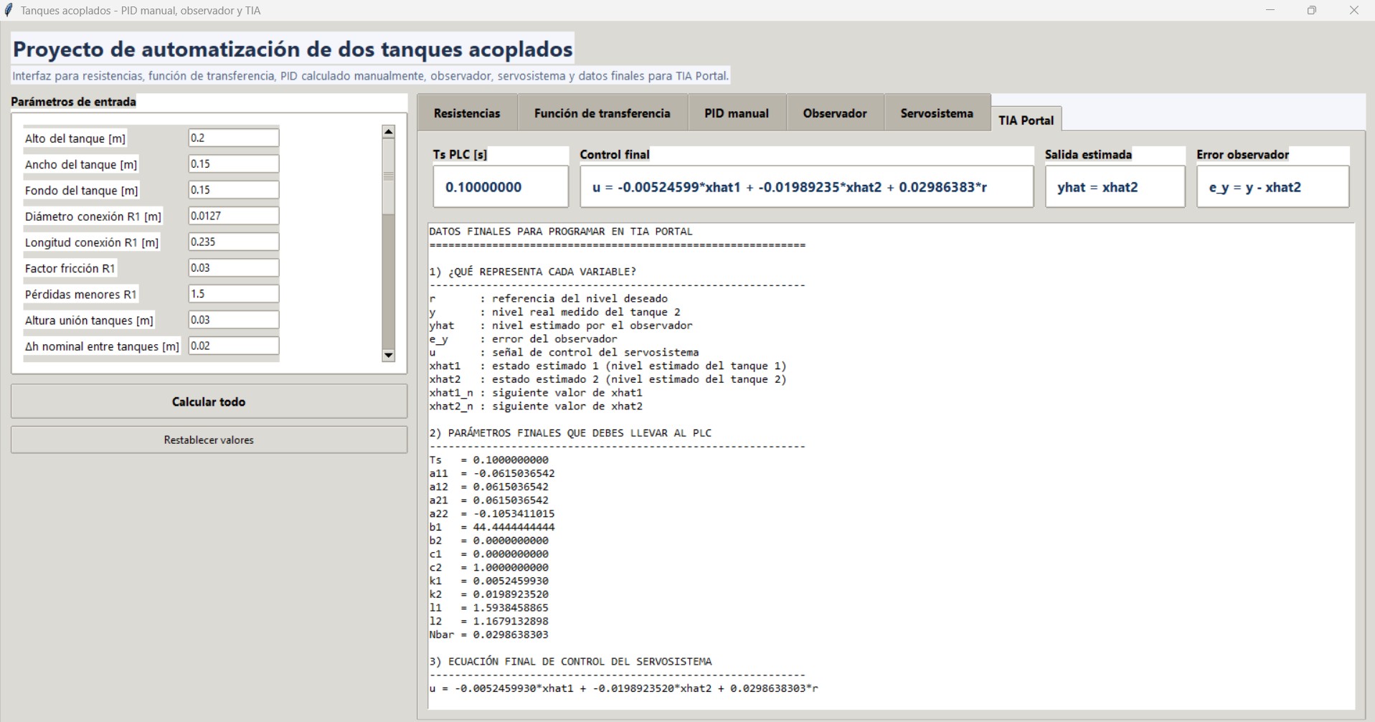
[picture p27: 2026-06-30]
Images/GUI6.jpg

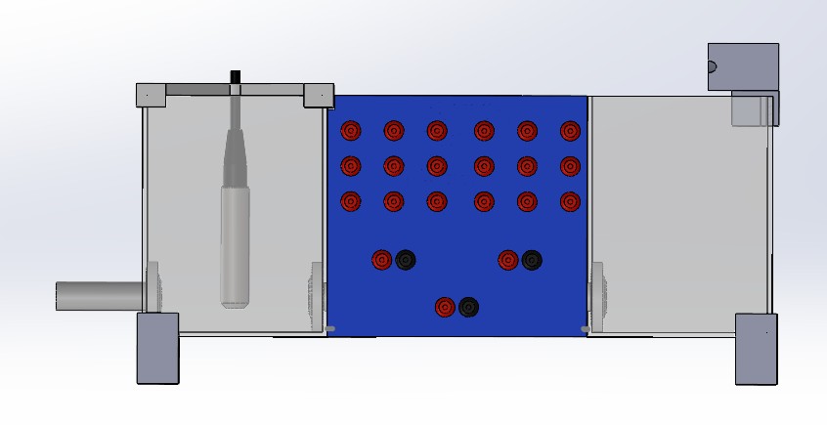
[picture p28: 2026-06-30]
Images/PARTE TRASERA CAD.jpg

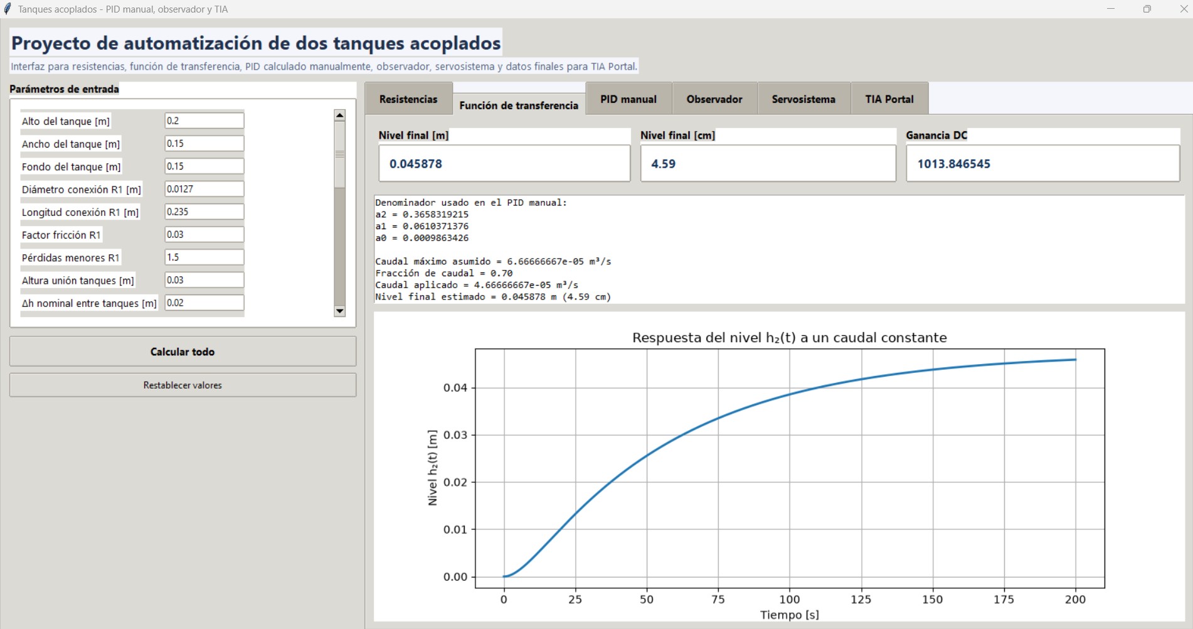
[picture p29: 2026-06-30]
Images/GUI2.jpg

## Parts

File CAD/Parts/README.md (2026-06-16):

# CAD Parts

SolidWorks part files (.SLDPRT) used in the Twin Tank Level Control System.

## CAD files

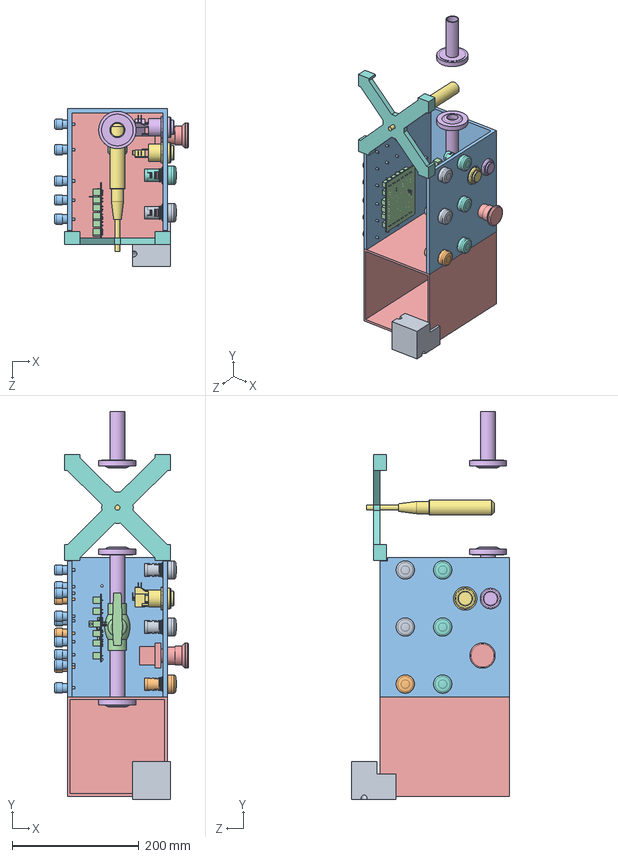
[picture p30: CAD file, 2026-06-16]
CAD/Assemblies/Ensamblaje planra.SLDASM
211.6 x 612.2 x 249.5 mm
soporte transmisor
transmisor
union tanque x 3
tanque 1
llave medio
soporte luces
Luz verde
luz roja x 2
luz amarilla x 3
boton parado
boton inicio
Boton de parada
pcbf
banana roja x 21
banana negra x 3
soporte manguera tanque 1

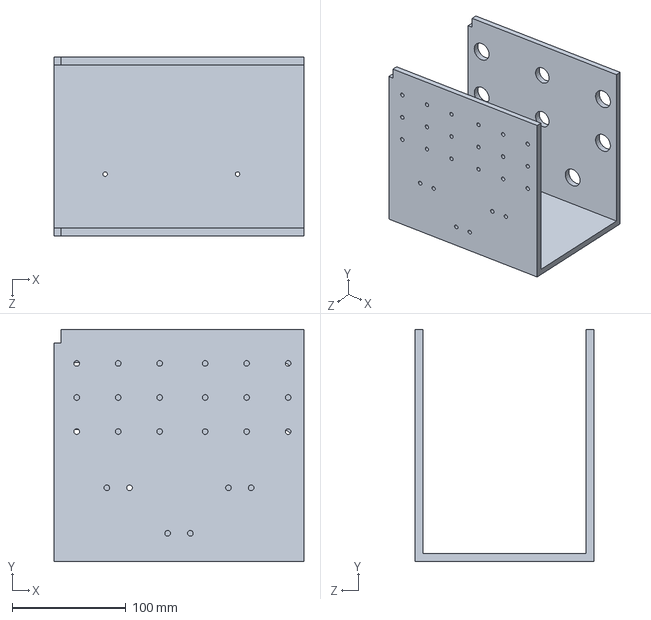
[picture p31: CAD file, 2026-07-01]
CAD/Parts/soporte luces.SLDPRT
220.0 x 204.5 x 157.6 mm

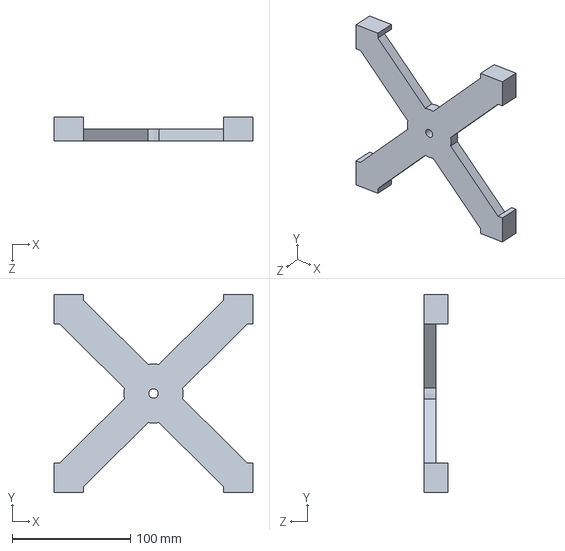
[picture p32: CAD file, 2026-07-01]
CAD/Parts/soporte transmisor.SLDPRT
168.0 x 167.3 x 20.0 mm

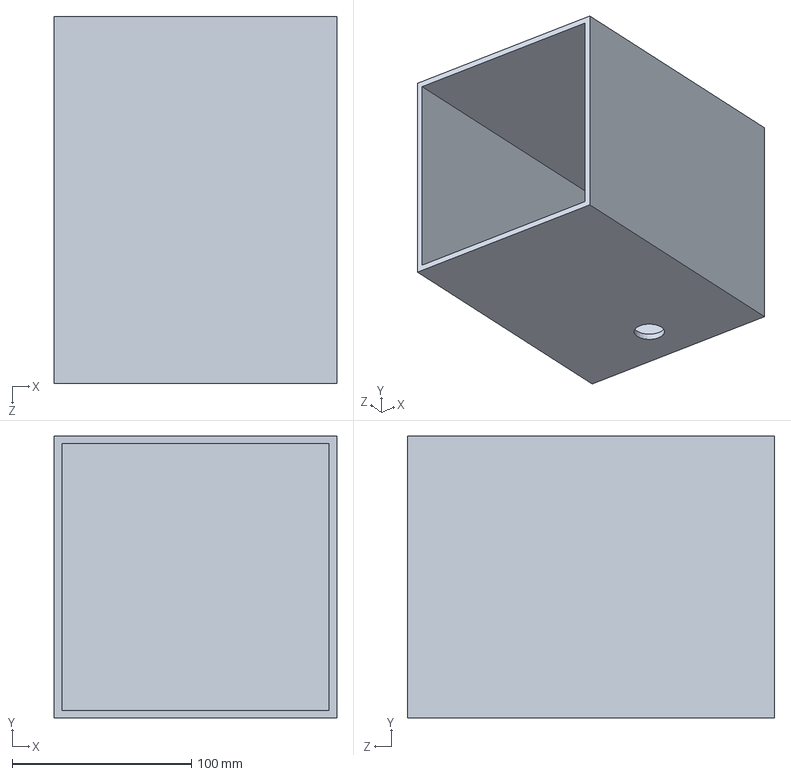
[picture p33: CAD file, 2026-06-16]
CAD/Parts/tanque 1.SLDPRT
157.6 x 157.1 x 204.5 mm

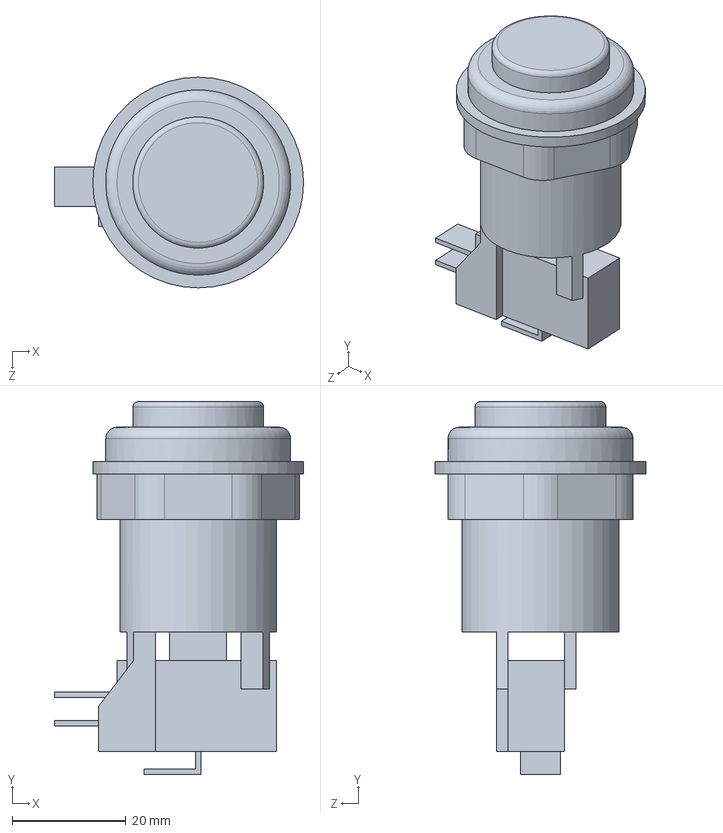
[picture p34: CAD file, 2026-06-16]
CAD/Parts/boton inicio.SLDPRT
43.8 x 65.5 x 37.0 mm

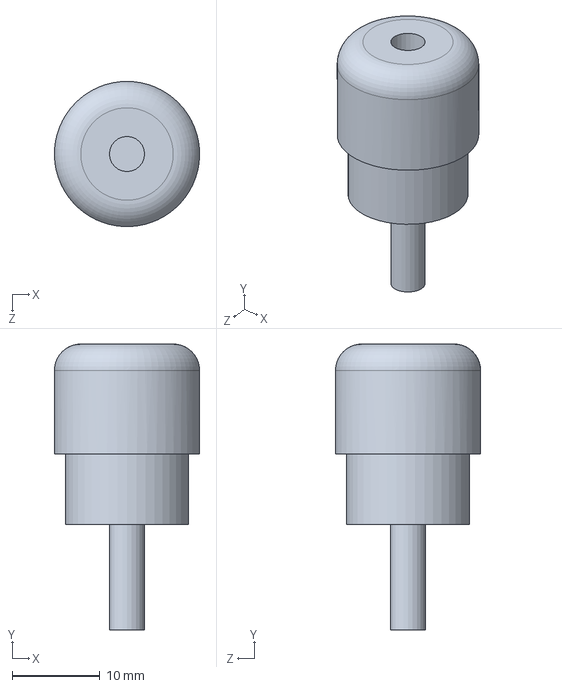
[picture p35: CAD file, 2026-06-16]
CAD/Parts/banana negra.SLDPRT
16.5 x 32.5 x 16.5 mm

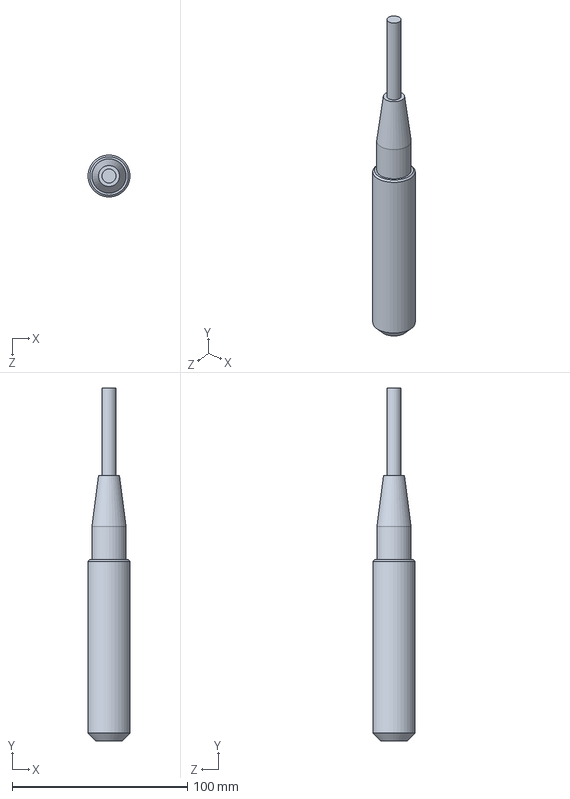
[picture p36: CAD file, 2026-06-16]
CAD/Parts/transmisor.SLDPRT
24.0 x 201.5 x 24.0 mm

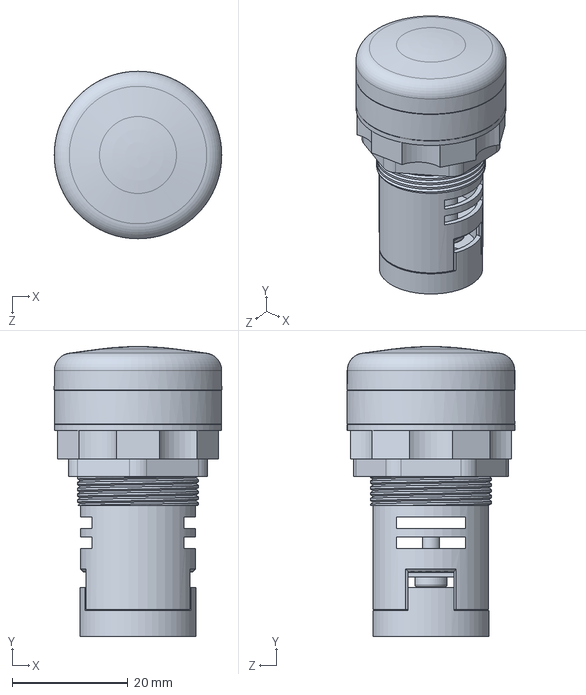
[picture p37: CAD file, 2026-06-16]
CAD/Parts/luz amarilla.SLDPRT
29.0 x 50.2 x 29.0 mm

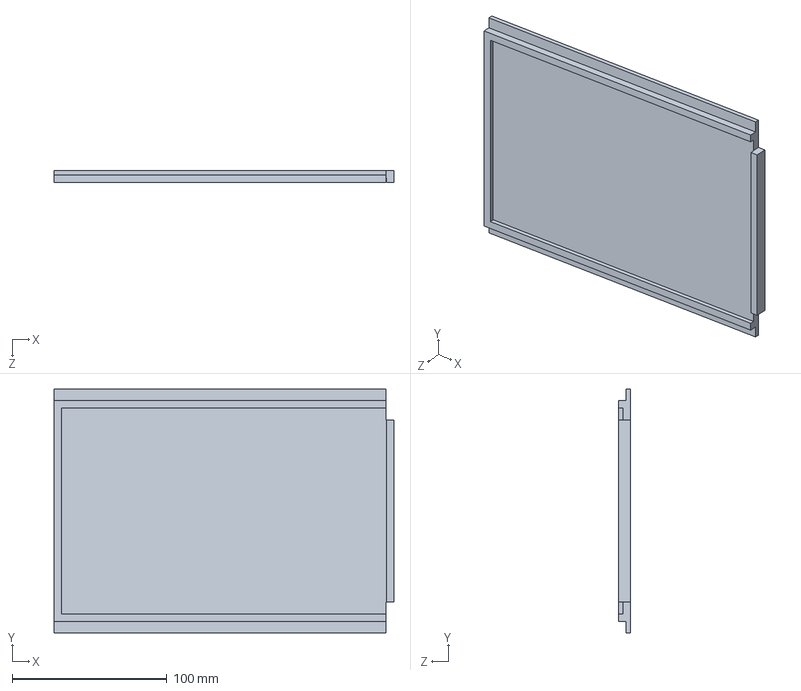
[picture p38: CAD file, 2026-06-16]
CAD/Parts/TAPA.SLDPRT
220.0 x 157.6 x 8.00 mm

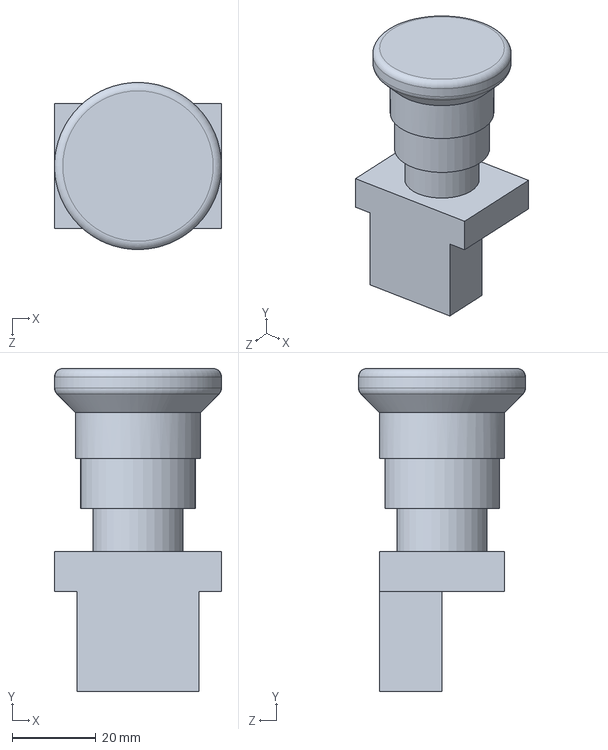
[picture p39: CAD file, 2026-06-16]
CAD/Parts/Boton de parada.SLDPRT
40.0 x 77.3 x 40.0 mm

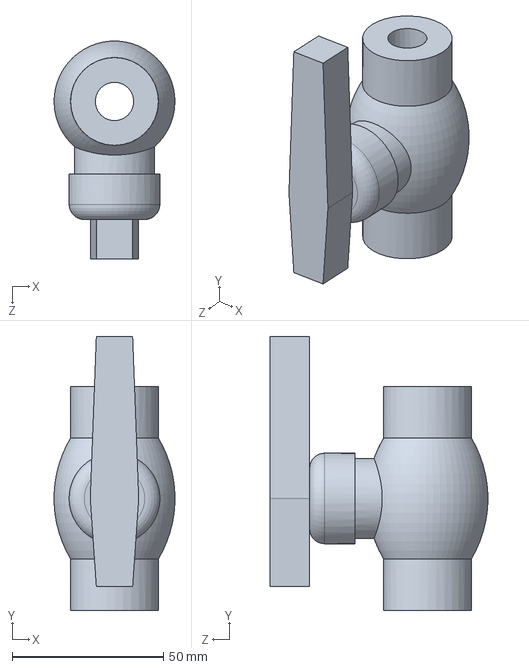
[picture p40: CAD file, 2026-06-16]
CAD/Parts/llave medio.SLDPRT
39.9 x 90.5 x 71.9 mm

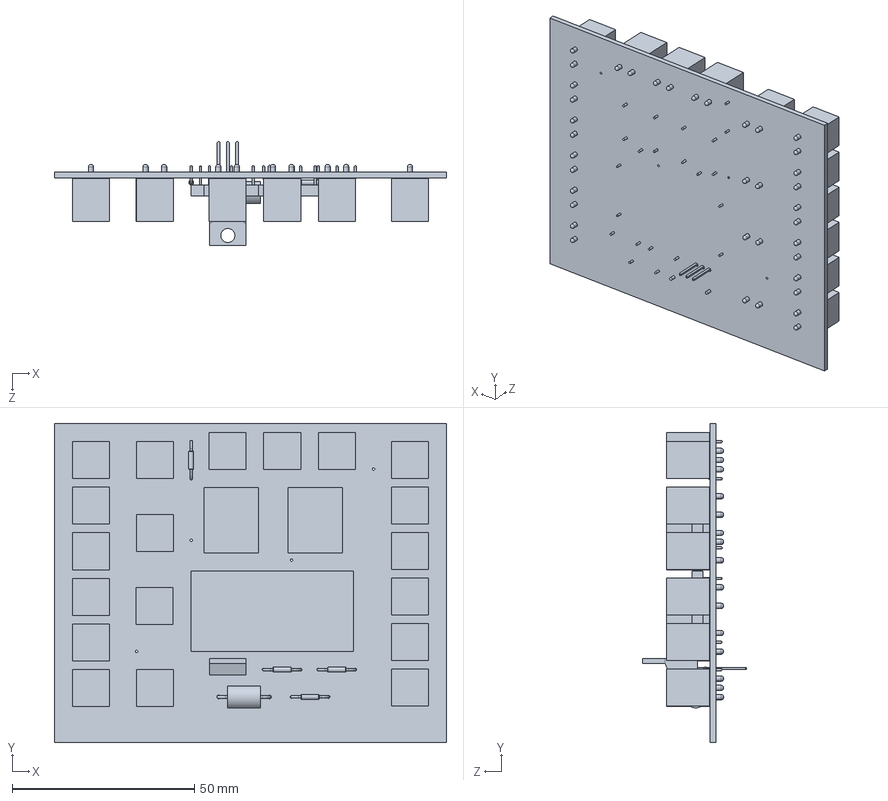
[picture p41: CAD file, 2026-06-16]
CAD/Parts/pcbf.SLDPRT
107.5 x 87.5 x 28.6 mm

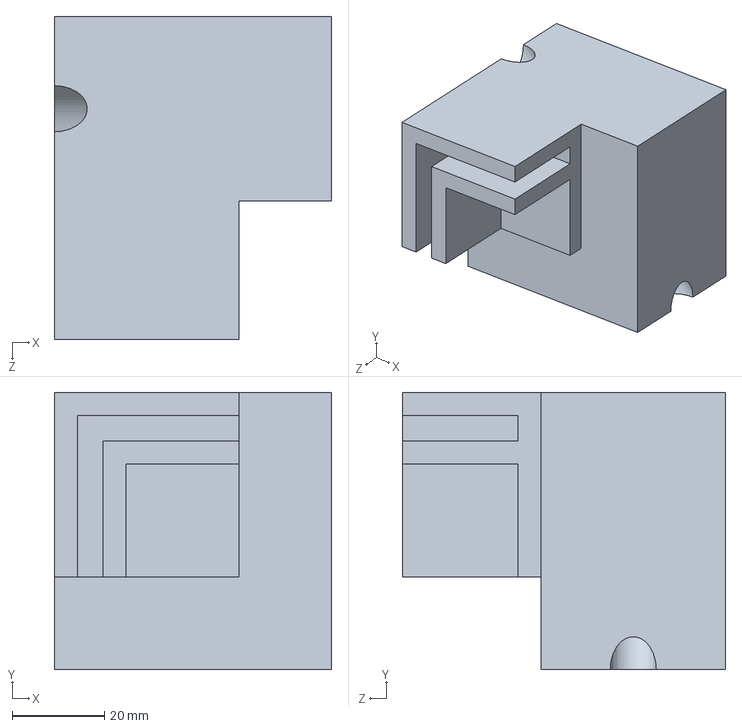
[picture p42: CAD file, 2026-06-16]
CAD/Parts/soporte manguera tanque 1.SLDPRT
60.0 x 60.0 x 70.0 mm

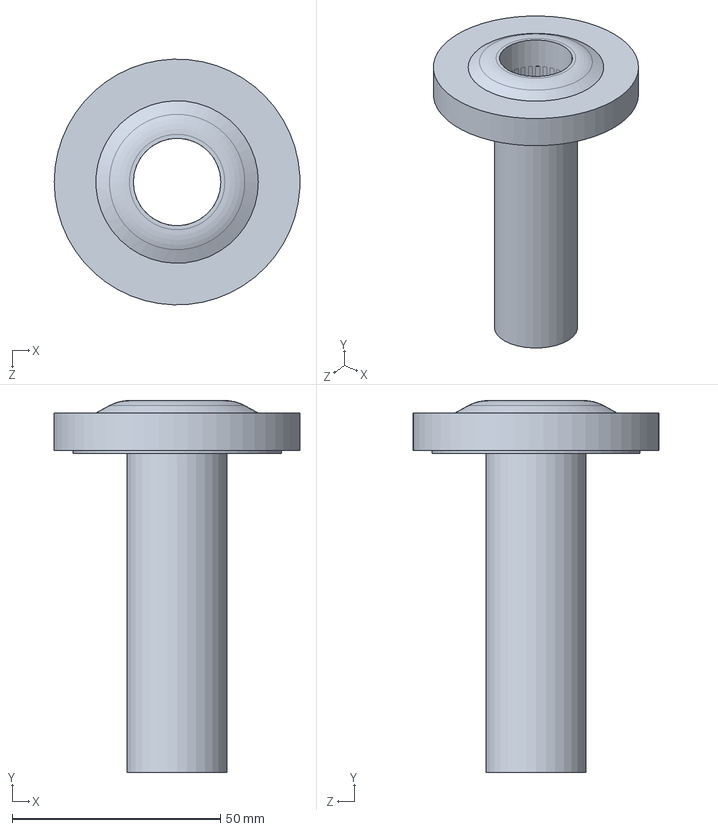
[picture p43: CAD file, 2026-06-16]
CAD/Parts/union tanque.SLDPRT
58.9 x 89.3 x 59.0 mm

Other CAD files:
CAD/Parts/banana roja.SLDPRT
CAD/Parts/Luz verde.SLDPRT
CAD/Parts/luz roja.SLDPRT
CAD/Parts/boton parado.SLDPRT
CAD/Parts/base tanques.SLDPRT
CAD/Parts/soporte luces copia.SLDPRT
CAD/Parts/tanque 2.SLDPRT

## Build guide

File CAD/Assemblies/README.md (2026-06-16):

# CAD Assemblies

SolidWorks assembly files (.SLDASM) of the complete system.

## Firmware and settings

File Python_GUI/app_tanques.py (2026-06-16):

import math
import tkinter as tk
from tkinter import ttk, messagebox

import numpy as np
import matplotlib.pyplot as plt
from matplotlib.backends.backend_tkagg import FigureCanvasTkAgg

try:
    import control as ctrl
except ImportError as exc:
    raise SystemExit("Falta la librería 'control'. Instálala con: pip install control") from exc


class ToolTip:
    def __init__(self, widget, text: str):
        self.widget = widget
        self.text = text
        self.tipwindow = None
        widget.bind("<Enter>", self.show)
        widget.bind("<Leave>", self.hide)

    def show(self, _event=None):
        if self.tipwindow or not self.text:
            return
        x = self.widget.winfo_rootx() + 20
        y = self.widget.winfo_rooty() + 20
        self.tipwindow = tw = tk.Toplevel(self.widget)
        tw.wm_overrideredirect(True)
        tw.wm_geometry(f"+{x}+{y}")
        label = tk.Label(
            tw,
            text=self.text,
            justify="left",
            background="#fffbe6",
            relief="solid",
            borderwidth=1,
            font=("Segoe UI", 9),
            wraplength=340,
            padx=8,
            pady=6,
        )
        label.pack()

    def hide(self, _event=None):
        if self.tipwindow:
            self.tipwindow.destroy()
            self.tipwindow = None


class TankApp:
    def __init__(self, root: tk.Tk):
        self.root = root
        self.root.title("Tanques acoplados - PID manual, observador y TIA")
        self.root.geometry("1540x940")
        self.root.configure(bg="#f4f6fb")

        self.vars = {}
        self.figures = {}
        self.metrics = {}
        self.models = {}

        self._build_style()
        self._build_ui()
        self._set_defaults()

    def _build_style(self):
        style = ttk.Style()
        try:
            style.theme_use("clam")
        except tk.TclError:
            pass

        style.configure("TNotebook", background="#f4f6fb")
        style.configure("TNotebook.Tab", padding=(16, 10), font=("Segoe UI", 10, "bold"))
        style.configure("Title.TLabel", font=("Segoe UI", 18, "bold"), foreground="#21314d", background="#f4f6fb")
        style.configure("Section.TLabelframe", background="#ffffff")
        style.configure("Section.TLabelframe.Label", font=("Segoe UI", 10, "bold"))
        style.configure("Info.TLabel", font=("Segoe UI", 10), background="#ffffff")
        style.configure("Metric.TLabel", font=("Segoe UI", 11, "bold"), background="#ffffff", foreground="#14345b")
        style.configure("Action.TButton", font=("Segoe UI", 10, "bold"), padding=8)

    def _fmt_num(self, x, nd=8):
        return f"{float(x):.{nd}f}"

    def _build_ui(self):
        main = ttk.Frame(self.root, padding=12)
        main.pack(fill="both", expand=True)

        header = ttk.Frame(main)
        header.pack(fill="x", pady=(0, 10))

        ttk.Label(
            header,
            text="Proyecto de automatización de dos tanques acoplados",
            style="Title.TLabel",
        ).pack(anchor="w")
        ttk.Label(
            header,
            text=(
                "Interfaz para resistencias, función de transferencia, PID calculado manualmente, "
                "observador, servosistema y datos finales para TIA Portal."
            ),
            font=("Segoe UI", 10),
            background="#f4f6fb",
            foreground="#50627d",
        ).pack(anchor="w", pady=(2, 0))

        body = ttk.Frame(main)
        body.pack(fill="both", expand=True)

        left = ttk.Frame(body)
        left.pack(side="left", fill="y", padx=(0, 10))

        right = ttk.Frame(body)
        right.pack(side="left", fill="both", expand=True)

        self._build_parameters_panel(left)
        self._build_notebook(right)

    def _build_parameters_panel(self, parent):
        card = ttk.LabelFrame(parent, text="Parámetros de entrada", style="Section.TLabelframe", padding=12)
        card.pack(fill="y", expand=False)

        fields = [
            ("alto_tanque", "Alto del tanque [m]", "Altura interna del tanque."),
            ("ancho_tanque", "Ancho del tanque [m]", "Ancho interno del tanque."),
            ("fondo_tanque", "Fondo del tanque [m]", "Profundidad interna del tanque."),
            ("D1", "Diámetro conexión R1 [m]", "Diámetro interno del tubo entre tanques."),
            ("L1", "Longitud conexión R1 [m]", "Longitud del tubo entre tanques."),
            ("f1", "Factor fricción R1", "Factor de fricción del tramo entre tanques."),
            ("Kminor1", "Pérdidas menores R1", "Suma de pérdidas menores entre tanques."),
            ("altura_union_tanques", "Altura unión tanques [m]", "Altura del tubo de unión respecto a la base."),
            ("Delta_h10", "Δh nominal entre tanques [m]", "Diferencia nominal h1-h2 para linealizar R1."),
            ("D2", "Diámetro salida R2 [m]", "Diámetro interno de la salida del tanque 2."),
            ("L2", "Longitud salida R2 [m]", "Longitud de la tubería de salida del tanque 2."),
            ("f2", "Factor fricción R2", "Factor de fricción de la salida."),
            ("Kminor2", "Pérdidas menores R2", "Suma de pérdidas menores en la salida."),
            ("nivel_nominal_t2", "Nivel nominal tanque 2 [m]", "Nivel de operación nominal del tanque 2."),
            ("altura_salida_t2", "Altura salida tanque 2 [m]", "Altura del eje de salida respecto a la base."),
            ("Qmax_Lh", "Caudal máximo bomba [L/h]", "Caudal máximo nominal de la bomba."),
            ("fraccion_caudal", "Fracción de caudal", "Fracción del caudal máximo usada en la simulación abierta."),
            ("href", "Referencia [m]", "Referencia para el servosistema."),
            ("Ts_obj", "Ts deseado [s]", "Tiempo de establecimiento deseado para el PID manual y el servosistema."),
            ("zeta", "Amortiguamiento ζ", "Amortiguamiento deseado."),
            ("alpha_factor", "Factor polo extra PID", "Factor usado para el polo adicional del PID: alpha = factor*wn."),
            ("factor_observador", "Factor observador", "Qué tan más rápido será el observador respecto a la planta."),
            ("x0h1_real", "x0 h1 real [m]", "Condición inicial real de h1."),
            ("x0h2_real", "x0 h2 real [m]", "Condición inicial real de h2."),
            ("x0h1_est", "x0 h1 estimado [m]", "Condición inicial estimada de h1."),
            ("x0h2_est", "x0 h2 estimado [m]", "Condición inicial estimada de h2."),
            ("tmax", "Tiempo simulación [s]", "Tiempo total de simulación."),
            ("dt", "Paso simulación [s]", "Paso de simulación y Ts sugerido para el PLC."),
        ]

        canvas = tk.Canvas(card, width=400, highlightthickness=0, bg="#ffffff")
        scrollbar = ttk.Scrollbar(card, orient="vertical", command=canvas.yview)
        scroll_frame = ttk.Frame(canvas)
        scroll_frame.bind("<Configure>", lambda e: canvas.configure(scrollregion=canvas.bbox("all")))
        canvas.create_window((0, 0), window=scroll_frame, anchor="nw")
        canvas.configure(yscrollcommand=scrollbar.set)
        canvas.pack(side="left", fill="both", expand=True)
        scrollbar.pack(side="right", fill="y")

        for idx, (key, label_text, tip) in enumerate(fields):
            label = ttk.Label(scroll_frame, text=label_text, style="Info.TLabel")
            label.grid(row=idx, column=0, sticky="w", padx=(0, 8), pady=4)
            ToolTip(label, tip)
            var = tk.StringVar()
            entry = ttk.Entry(scroll_frame, textvariable=var, width=16)
            entry.grid(row=idx, column=1, sticky="ew", pady=4)
            ToolTip(entry, tip)
            self.vars[key] = var

        scroll_frame.columnconfigure(1, weight=1)

        btns = ttk.Frame(parent)
        btns.pack(fill="x", pady=(10, 0))
        ttk.Button(btns, text="Calcular todo", style="Action.TButton", command=self.calculate_all).pack(fill="x")
        ttk.Button(btns, text="Restablecer valores", command=self._set_defaults).pack(fill="x", pady=(8, 0))

    def _build_notebook(self, parent):
        notebook = ttk.Notebook(parent)
        notebook.pack(fill="both", expand=True)

        self.tab_res = ttk.Frame(notebook, padding=10)
        self.tab_tf = ttk.Frame(notebook, padding=10)
        self.tab_pid = ttk.Frame(notebook, padding=10)
        self.tab_obs = ttk.Frame(notebook, padding=10)
        self.tab_servo = ttk.Frame(notebook, padding=10)
        self.tab_tia = ttk.Frame(notebook, padding=10)

        notebook.add(self.tab_res, text="Resistencias")
        notebook.add(self.tab_tf, text="Función de transferencia")
        notebook.add(self.tab_pid, text="PID manual")
        notebook.add(self.tab_obs, text="Observador")
        notebook.add(self.tab_servo, text="Servosistema")
        notebook.add(self.tab_tia, text="TIA Portal")

        self._build_res_tab()
        self._build_tf_tab()
        self._build_pid_tab()
        self._build_obs_tab()
        self._build_servo_tab()
        self._build_tia_tab()

    def _metric_box(self, parent, title, key, tip):
        frame = ttk.LabelFrame(parent, text=title, style="Section.TLabelframe", padding=10)
        ttk.Label(frame, textvariable=self.metrics.setdefault(key, tk.StringVar(value="-")), style="Metric.TLabel").pack(anchor="w")
        ToolTip(frame, tip)
        return frame

    def _build_res_tab(self):
        top = ttk.Frame(self.tab_res)
        top.pack(fill="x")
        boxes = [
            ("R1 estimada", "R1", "Resistencia hidráulica equivalente entre tanque 1 y tanque 2."),
            ("R2 estimada", "R2", "Resistencia hidráulica equivalente en la salida del tanque 2."),
            ("Kh1", "Kh1", "Constante hidráulica no lineal del tramo entre tanques."),
            ("Kh2", "Kh2", "Constante hidráulica no lineal de la salida."),
        ]
        for i, (title, key, tip) in enumerate(boxes):
            box = self._metric_box(top, title, key, tip)
            box.grid(row=0, column=i, sticky="nsew", padx=6, pady=6)
            top.columnconfigure(i, weight=1)

        self.res_text = tk.Text(self.tab_res, height=18, wrap="word", font=("Consolas", 10))
        self.res_text.pack(fill="both", expand=True, pady=(10, 0))

    def _build_tf_tab(self):
        top = ttk.Frame(self.tab_tf)
        top.pack(fill="x")
        boxes = [
            ("Nivel final [m]", "nivel_final", "Valor final aproximado del nivel del tanque 2."),
            ("Nivel final [cm]", "nivel_final_cm", "Valor final aproximado en centímetros."),
            ("Ganancia DC", "ganancia_dc", "Ganancia estática de la función de transferencia."),
        ]
        for i, (title, key, tip) in enumerate(boxes):
            box = self._metric_box(top, title, key, tip)
            box.grid(row=0, column=i, sticky="nsew", padx=6, pady=6)
            top.columnconfigure(i, weight=1)

        self.tf_text = tk.Text(self.tab_tf, height=9, wrap="word", font=("Consolas", 10))
        self.tf_text.pack(fill="x", pady=(10, 10))

        fig = plt.Figure(figsize=(8, 5), dpi=100)
        self.figures["tf"] = fig
        self.tf_canvas = FigureCanvasTkAgg(fig, master=self.tab_tf)
        self.tf_canvas.get_tk_widget().pack(fill="both", expand=True)

    def _build_pid_tab(self):
        top = ttk.Frame(self.tab_pid)
        top.pack(fill="x")
        boxes = [
            ("Kp manual", "Kp", "Ganancia proporcional calculada manualmente por comparación de coeficientes."),
            ("Ki manual", "Ki", "Ganancia integral calculada manualmente por comparación de coeficientes."),
            ("Kd manual", "Kd", "Ganancia derivativa calculada manualmente por comparación de coeficientes."),
            ("Polo extra α", "alpha_pid", "Polo adicional usado en el diseño manual del PID."),
        ]
        for i, (title, key, tip) in enumerate(boxes):
            box = self._metric_box(top, title, key, tip)
            box.grid(row=0, column=i, sticky="nsew", padx=6, pady=6)
            top.columnconfigure(i, weight=1)

        self.pid_text = tk.Text(self.tab_pid, height=18, wrap="word", font=("Consolas", 10))
        self.pid_text.pack(fill="x", pady=(10, 10))

        container = ttk.Frame(self.tab_pid)
        container.pack(fill="both", expand=True)

        fig1 = plt.Figure(figsize=(7, 4), dpi=100)
        self.figures["pid_resp"] = fig1
        self.pid_resp_canvas = FigureCanvasTkAgg(fig1, master=container)
        self.pid_resp_canvas.get_tk_widget().pack(side="left", fill="both", expand=True)

        fig2 = plt.Figure(figsize=(7, 4), dpi=100)
        self.figures["pid_u"] = fig2
        self.pid_u_canvas = FigureCanvasTkAgg(fig2, master=container)
        self.pid_u_canvas.get_tk_widget().pack(side="left", fill="both", expand=True)

    def _build_obs_tab(self):
        top = ttk.Frame(self.tab_obs)
        top.pack(fill="x")
        boxes = [
            ("Rango controlabilidad", "rango_ctrl", "Rango de la matriz de controlabilidad."),
            ("Rango observabilidad", "rango_obs", "Rango de la matriz de observabilidad."),
            ("e1 final [m]", "e1_final", "Error final de estimación del estado 1."),
            ("e2 final [m]", "e2_final", "Error final de estimación del estado 2."),
        ]
        for i, (title, key, tip) in enumerate(boxes):
            box = self._metric_box(top, title, key, tip)
            box.grid(row=0, column=i, sticky="nsew", padx=6, pady=6)
            top.columnconfigure(i, weight=1)

        self.obs_text = tk.Text(self.tab_obs, height=12, wrap="word", font=("Consolas", 10))
        self.obs_text.pack(fill="x", pady=(10, 10))

        container = ttk.Frame(self.tab_obs)
        container.pack(fill="both", expand=True)

        fig1 = plt.Figure(figsize=(5.3, 4), dpi=100)
        self.figures["obs_h1"] = fig1
        self.obs_h1_canvas = FigureCanvasTkAgg(fig1, master=container)
        self.obs_h1_canvas.get_tk_widget().pack(side="left", fill="both", expand=True)

        fig2 = plt.Figure(figsize=(5.3, 4), dpi=100)
        self.figures["obs_h2"] = fig2
        self.obs_h2_canvas = FigureCanvasTkAgg(fig2, master=container)
        self.obs_h2_canvas.get_tk_widget().pack(side="left", fill="both", expand=True)

        fig3 = plt.Figure(figsize=(5.3, 4), dpi=100)
        self.figures["obs_err"] = fig3
        self.obs_err_canvas = FigureCanvasTkAgg(fig3, master=container)
        self.obs_err_canvas.get_tk_widget().pack(side="left", fill="both", expand=True)

    def _build_servo_tab(self):
        top = ttk.Frame(self.tab_servo)
        top.pack(fill="x")
        boxes = [
            ("K = [k1 k2]", "K_servo", "Ganancia de realimentación de estados."),
            ("Nbar", "Nbar", "Precompensador para seguimiento de referencia."),
            ("L = [l1 l2]", "L_servo", "Ganancia del observador usada en el servosistema."),
            ("Error final [cm]", "servo_error_final_cm", "Error final de seguimiento del servosistema."),
        ]
        for i, (title, key, tip) in enumerate(boxes):
            box = self._metric_box(top, title, key, tip)
            box.grid(row=0, column=i, sticky="nsew", padx=6, pady=6)
            top.columnconfigure(i, weight=1)

        self.servo_text = tk.Text(self.tab_servo, height=10, wrap="word", font=("Consolas", 10))
        self.servo_text.pack(fill="x", pady=(10, 10))

        container = ttk.Frame(self.tab_servo)
        container.pack(fill="both", expand=True)

        fig1 = plt.Figure(figsize=(5.3, 4), dpi=100)
        self.figures["servo_y"] = fig1
        self.servo_y_canvas = FigureCanvasTkAgg(fig1, master=container)
        self.servo_y_canvas.get_tk_widget().pack(side="left", fill="both", expand=True)

        fig2 = plt.Figure(figsize=(5.3, 4), dpi=100)
        self.figures["servo_states"] = fig2
        self.servo_states_canvas = FigureCanvasTkAgg(fig2, master=container)
        self.servo_states_canvas.get_tk_widget().pack(side="left", fill="both", expand=True)

        fig3 = plt.Figure(figsize=(5.3, 4), dpi=100)
        self.figures["servo_u"] = fig3
        self.servo_u_canvas = FigureCanvasTkAgg(fig3, master=container)
        self.servo_u_canvas.get_tk_widget().pack(side="left", fill="both", expand=True)

    def _build_tia_tab(self):
        top = ttk.Frame(self.tab_tia)
        top.pack(fill="x")
        boxes = [
            ("Ts PLC [s]", "tia_ts", "Tiempo de muestreo usado en las ecuaciones discretas."),
            ("Control final", "tia_control", "Ecuación final del servosistema."),
            ("Salida estimada", "tia_yhat", "Ecuación final de la salida estimada."),
            ("Error observador", "tia_ey", "Ecuación final del error del observador."),
        ]
        for i, (title, key, tip) in enumerate(boxes):
            box = self._metric_box(top, title, key, tip)
            box.grid(row=0, column=i, sticky="nsew", padx=6, pady=6)
            top.columnconfigure(i, weight=1)

        self.tia_text = tk.Text(self.tab_tia, height=30, wrap="word", font=("Consolas", 10))
        self.tia_text.pack(fill="both", expand=True, pady=(10, 0))

    def _set_defaults(self):
        defaults = {
            "alto_tanque": 0.20,
            "ancho_tanque": 0.15,
            "fondo_tanque": 0.15,
            "D1": 0.0127,
            "L1": 0.235,
            "f1": 0.03,
            "Kminor1": 1.5,
            "altura_union_tanques": 0.03,
            "Delta_h10": 0.02,
            "D2": 0.0127,
            "L2": 0.05,
            "f2": 0.03,
            "Kminor2": 1.5,
            "nivel_nominal_t2": 0.08,
            "altura_salida_t2": 0.03,
            "Qmax_Lh": 240.0,
            "fraccion_caudal": 0.70,
            "href": 0.10,
            "Ts_obj": 20.0,
            "zeta": 0.7,
            "alpha_factor": 5.0,
            "factor_observador": 8.0,
            "x0h1_real": 0.0,
            "x0h2_real": 0.0,
            "x0h1_est": 0.02,
            "x0h2_est": 0.01,
            "tmax": 200.0,
            "dt": 0.1,
        }
        for key, value in defaults.items():
            self.vars[key].set(str(value))

    def _get_float(self, key):
        try:
            return float(self.vars[key].get())
        except ValueError as exc:
            raise ValueError(f"Valor inválido en '{key}'.") from exc

    def _collect_inputs(self):
        data = {key: self._get_float(key) for key in self.vars}
        if data["nivel_nominal_t2"] <= data["altura_salida_t2"]:
            raise ValueError("El nivel nominal del tanque 2 debe ser mayor que la altura de la salida.")
        if data["Delta_h10"] <= 0:
            raise ValueError("La diferencia nominal entre tanques debe ser mayor que cero.")
        if data["dt"] <= 0 or data["tmax"] <= 0:
            raise ValueError("El tiempo total y el paso deben ser mayores que cero.")
        return data

    def calculate_all(self):
        try:
            p = self._collect_inputs()
            self._calculate_resistances(p)
            self._calculate_transfer_function(p)
            self._calculate_pid_manual(p)
            self._calculate_observer(p)
            self._calculate_servo(p)
            messagebox.showinfo("Cálculo completado", "Se actualizaron las pestañas con el PID manual y los datos corregidos de TIA.")
        except Exception as exc:
            messagebox.showerror("Error", str(exc))

    def _calculate_resistances(self, p):
        g = 9.81
        A_tanque = p["ancho_tanque"] * p["fondo_tanque"]
        At1 = math.pi * p["D1"] ** 2 / 4
        At2 = math.pi * p["D2"] ** 2 / 4
        Delta_h20 = p["nivel_nominal_t2"] - p["altura_salida_t2"]

        Kh1 = (p["f1"] * (p["L1"] / p["D1"]) + p["Kminor1"]) / (2 * g * At1 ** 2)
        R1 = 2 * math.sqrt(Kh1 * p["Delta_h10"])
        Kh2 = (p["f2"] * (p["L2"] / p["D2"]) + p["Kminor2"]) / (2 * g * At2 ** 2)
        R2 = 2 * math.sqrt(Kh2 * Delta_h20)

        self.models.update({
            "A_tanque": A_tanque,
            "At1": At1,
            "At2": At2,
            "Kh1": Kh1,
            "Kh2": Kh2,
            "R1": R1,
            "R2": R2,
            "Delta_h20": Delta_h20,
        })

        self.metrics["R1"].set(f"{R1:.4f} s/m²")
        self.metrics["R2"].set(f"{R2:.4f} s/m²")
        self.metrics["Kh1"].set(f"{Kh1:.4e}")
        self.metrics["Kh2"].set(f"{Kh2:.4e}")

        text = (
            "RESUMEN DE RESISTENCIAS HIDRÁULICAS\n"
            f"Área del tanque A = {A_tanque:.6f} m²\n"
            f"Área interna tubo R1 = {At1:.8f} m²\n"
            f"Área interna tubo R2 = {At2:.8f} m²\n"
            f"Δh10 nominal = {p['Delta_h10']:.4f} m\n"
            f"Δh20 efectivo = {Delta_h20:.4f} m\n"
            f"Kh1 = {Kh1:.4e}\n"
            f"Kh2 = {Kh2:.4e}\n"
            f"R1 = {R1:.6f} s/m²\n"
            f"R2 = {R2:.6f} s/m²\n"
        )
        self.res_text.delete("1.0", tk.END)
        self.res_text.insert(tk.END, text)

    def _calculate_transfer_function(self, p):
        A_tanque = self.models["A_tanque"]
        R1 = self.models["R1"]
        R2 = self.models["R2"]

        num = [1.0]
        den = [A_tanque ** 2 * R1, A_tanque * (2 + R1 / R2), 1.0 / R2]
        G = ctrl.tf(num, den)
        self.models["G"] = G
        self.models["den_G"] = den

        Qmax = (p["Qmax_Lh"] / 1000.0) / 3600.0
        Qin_constante = p["fraccion_caudal"] * Qmax
        t = np.arange(0, p["tmax"] + p["dt"], p["dt"])
        u = Qin_constante * np.ones_like(t)
        t_out, y_out = ctrl.forced_response(G, T=t, U=u)

        ganancia_dc = ctrl.dcgain(G)
        nivel_final = float(y_out[-1])

        self.metrics["nivel_final"].set(f"{nivel_final:.6f}")
        self.metrics["nivel_final_cm"].set(f"{nivel_final * 100:.2f}")
        self.metrics["ganancia_dc"].set(f"{float(ganancia_dc):.6f}")
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

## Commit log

2026-06-16 Create README.md for CAD models
    Add README file for CAD models documentation
2026-06-16 Add README for CAD Parts directory
2026-06-16 Add README for CAD Assemblies
2026-06-16 Create README.md for PCB models
    Add README for PCB models and enclosure integration.
2026-06-16 Add SolidWorks CAD part files
    [Boton de parada.SLDPRT, Luz verde.SLDPRT, TAPA.SLDPRT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]
2026-06-16 add ensamblaje planra file
    [Ensamblaje planra.SLDASM]
2026-06-30 Complete initial project structure
    Added CAD models, MATLAB scripts, Python GUI, project images, documentation and Python requirements.
2026-07-01 Finalize portfolio documentation and project structure
    Updated README, added project documentation, requirements file, folder descriptions, and improved repository organization for portfolio presentation.
    [soporte luces.SLDPRT, soporte transmisor.SLDPRT]
